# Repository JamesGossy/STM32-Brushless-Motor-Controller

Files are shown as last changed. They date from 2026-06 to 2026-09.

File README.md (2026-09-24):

<div align="center">

# STM32 Brushless Motor Controller

A custom four-layer motor controller with bare-metal field-oriented control on an STM32G474. The project includes the PCB design, C firmware, a motor simulator and a live control dashboard.

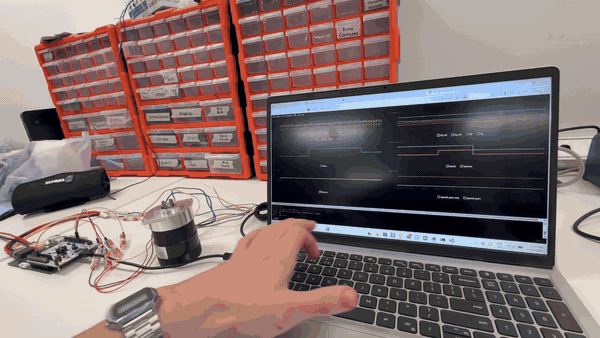
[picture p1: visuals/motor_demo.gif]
Bench demo of a real motor running alongside the live telemetry dashboard


*Real motor bench test with the live telemetry dashboard.*

</div>

## Engineering overview

- **Hardware:** a 57 × 75 mm PCB with six MOSFETs, three low-side current shunts, absolute encoder feedback and CAN connectivity.
- **Control:** 20 kHz d/q current loops and SVPWM, a 2 kHz speed loop, decoupling feedforward and field weakening.
- **Firmware:** bare-metal C using CMSIS headers, with register-level peripheral drivers and no STM32 HAL dependency. The application code also runs in the software-in-the-loop simulator.
- **Calibration and protection:** current-sense polarity and encoder calibration, stored settings, and checks for current, voltage, temperature, encoder and communication faults.
- **Tools:** a browser dashboard for commands and telemetry, plus unit tests and simulated motor/fault scenarios.

```mermaid
flowchart LR
    control["STM32G474<br/>Field-oriented control"]
    power["DRV8353S & MOSFETs<br/>Three-phase bridge"]
    motor["BLDC / PMSM motor"]
    control -->|PWM| power --> motor
    motor -->|Current & rotor position| control

    classDef controller fill:#eef2ff,stroke:#6366f1,color:#1e1b4b
    classDef drive fill:#ecfdf5,stroke:#059669,color:#064e3b
    class control controller
    class power,motor drive
```

## Hardware

<p align="center">
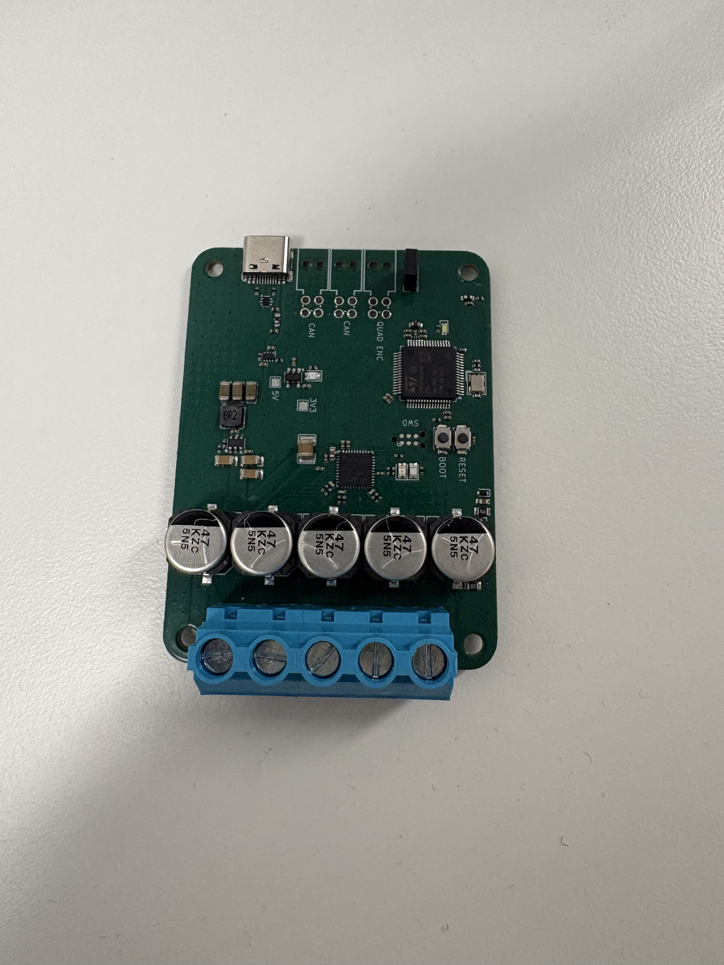
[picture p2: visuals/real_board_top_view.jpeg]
Top of the assembled board showing the MCU, gate driver and bulk capacitors
  
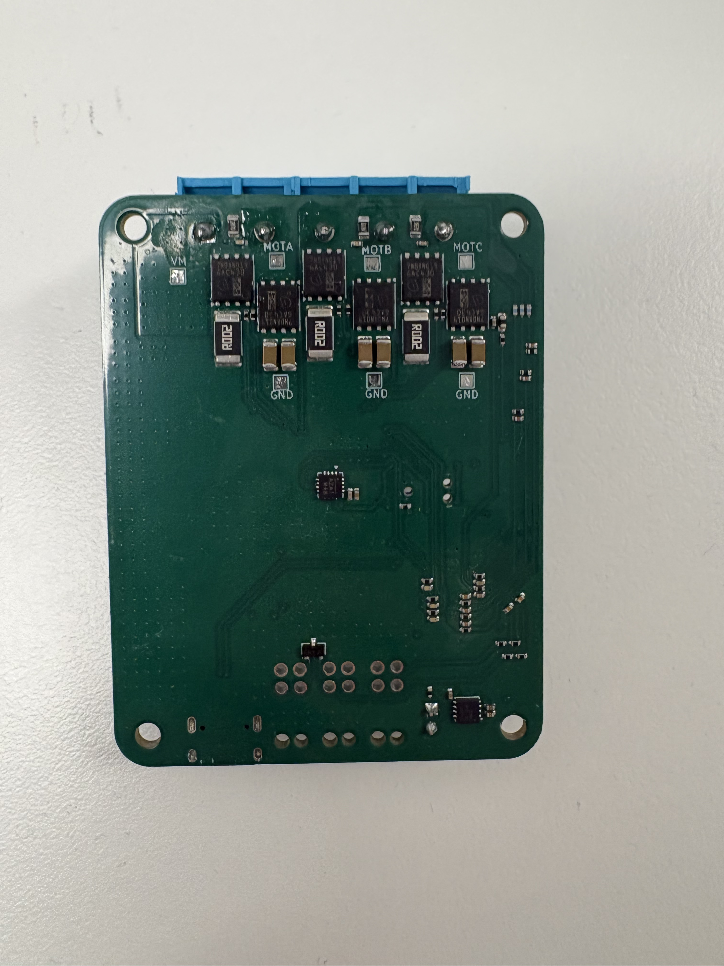
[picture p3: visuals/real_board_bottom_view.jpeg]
Bottom of the assembled board showing the MOSFET bridge and current shunts
  
</p>

| Item | Design |
| --- | --- |
| MCU | STM32G474RET6, 170 MHz |
| Gate driver | TI DRV8353S, configured over SPI |
| Input range | 12–60 V design target |
| Phase current | 25 A continuous design target; firmware defaults to a 20 A limit |
| MOSFETs | Six IAUCN08S7N019ATMA1, 80 V |
| Current sensing | Three 2 mΩ shunts with Kelvin connections |
| Position feedback | MA730 SPI encoder; external quadrature interface |
| PWM | HRTIM, 20 kHz, 200 ns dead time |
| Interfaces | CAN, USB CDC, UART and SWD |
| PCB | 57 × 75 mm, four layers |

The layout keeps gate-drive loops short, separates current-sense connections from power routing, and uses copper pours and via arrays to distribute current and heat. KiCad sources and manufacturing files are in [`controller_hardware/`](controller_hardware/).

## Live dashboard

<p align="center">
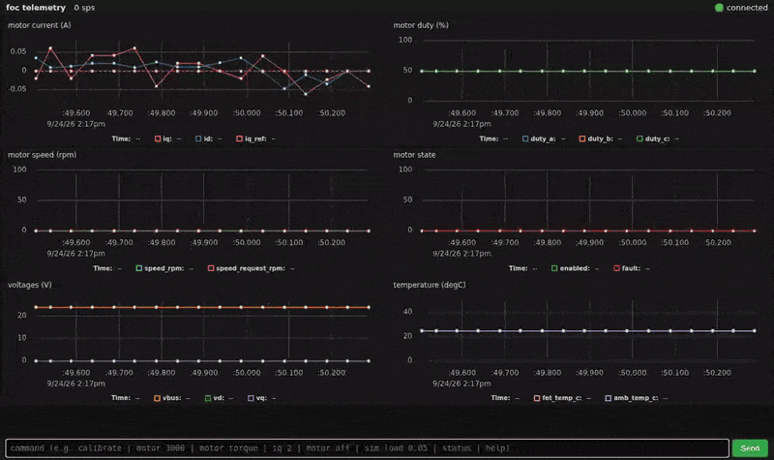
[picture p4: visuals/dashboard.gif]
Browser dashboard controlling the simulated motor and plotting telemetry
  
</p>

The dashboard connects to either the simulator or a board over USB. It shows motor telemetry and accepts commands for speed, torque, calibration and fault handling. The GIF above shows the simulator.

## Try the simulator

On Windows, run `controller_firmware\tools\setup.bat` to install missing tools, build the simulator and run tests. Then run `controller_firmware\tools\dashboard.bat` to open the dashboard.

For a manual build, install CMake, Ninja, a host C compiler and Python:

```sh
cd controller_firmware
cmake --preset sim
cmake --build --preset sim
ctest --preset sim
python -m pip install -r tools/dashboard/requirements.txt
python tools/dashboard/plot_motor.py --sim
```

Open [localhost:8988](http://localhost:8988). In the dashboard console, run `calibrate`, then `motor 3000` to request 3,000 rpm. Use `motor off` to stop. Simulator commands such as `sim load 0.1` and `sim lock on` exercise load response and fault handling.

## Build for the board

Install STM32CubeCLT and put its Arm compiler, CMake, Ninja and STM32 programmer on PATH. From `controller_firmware/`:

```sh
cmake --preset default
cmake --build --preset default
cmake --build build --target flash
```

Flashing uses ST-Link over SWD. To connect the dashboard to the board:

```sh
python tools/dashboard/plot_motor.py --serial COM5
```

Set the motor parameters and limits in [`app/config.h`](controller_firmware/app/config.h) before running hardware. Start with a current-limited supply and an unloaded motor, then run calibration before requesting motion.

## Validation and limits

C tests cover control maths, SVPWM, configuration, commands and telemetry. Software-in-the-loop tests exercise calibration, torque and speed response, field weakening, CAN control and fault handling. CI builds the firmware and runs simulator and dashboard tests on Linux and Windows.

The electrical ratings above are design targets; simulation does not establish continuous-current capability or thermal performance. This board revision has no on-board reverse-polarity protection, fuse or bus TVS.

## Code guide

| Location | Contents |
| --- | --- |
| [`controller_hardware/`](controller_hardware/) | KiCad schematics, PCB layout and manufacturing files |
| [`controller_firmware/app/`](controller_firmware/app/) | FOC, control loops, calibration, commands and telemetry |
| [`controller_firmware/hal/stm32g474/`](controller_firmware/hal/stm32g474/) | HRTIM, ADC, encoder, gate-driver, CAN and USB drivers |
| [`controller_firmware/sim/`](controller_firmware/sim/) | Simulated hardware interface, motor model and TCP server |
| [`controller_firmware/tests/`](controller_firmware/tests/) | Unit and motor simulation tests |
| [`controller_firmware/tools/dashboard/`](controller_firmware/tools/dashboard/) | Browser dashboard and Python bridge |

MIT licensed. Copyright © 2026 James Goss.

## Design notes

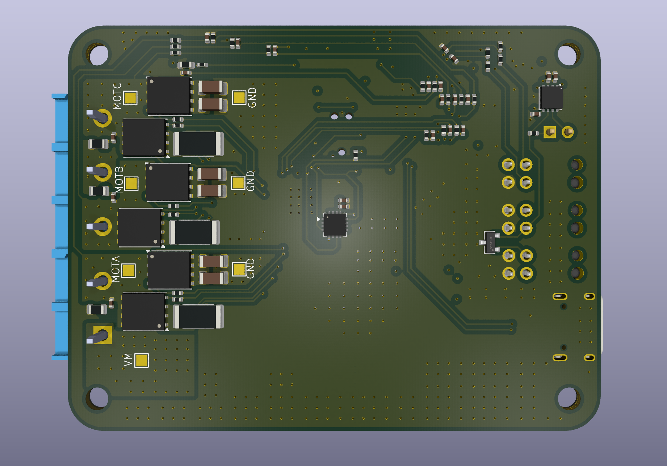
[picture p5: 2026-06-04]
visuals/bottom_view.png

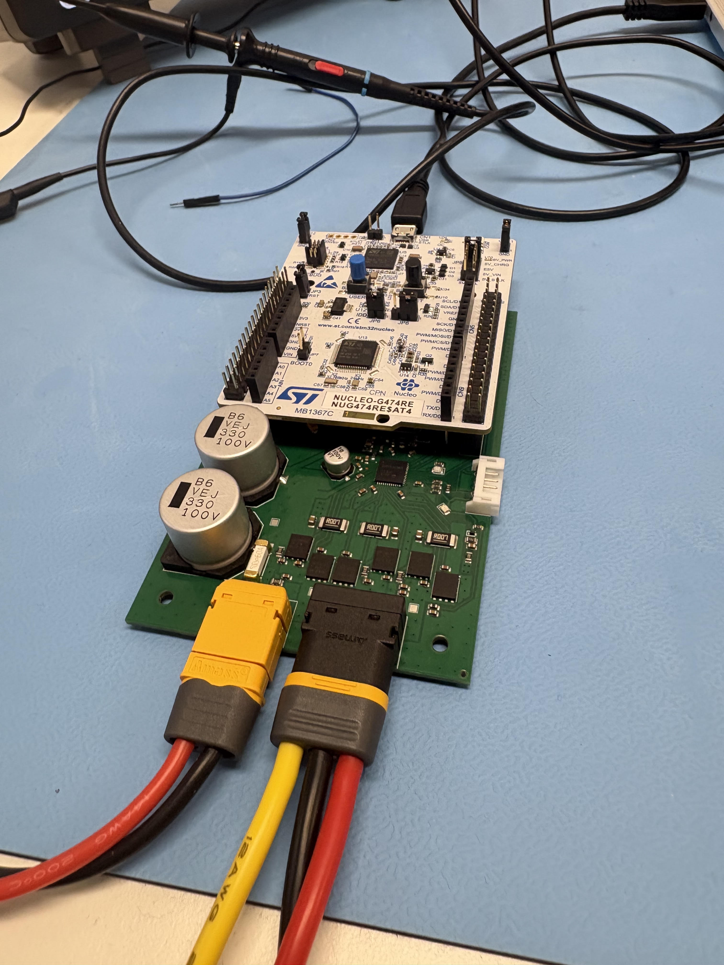
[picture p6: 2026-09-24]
visuals/rev1_board.jpg

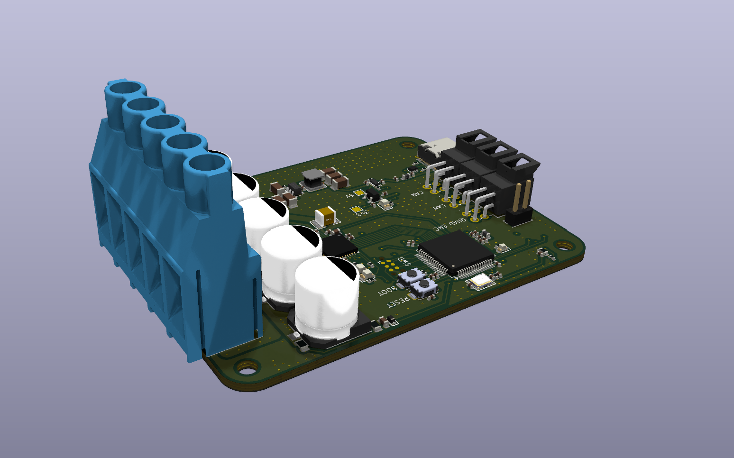
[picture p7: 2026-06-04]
visuals/side_view.png

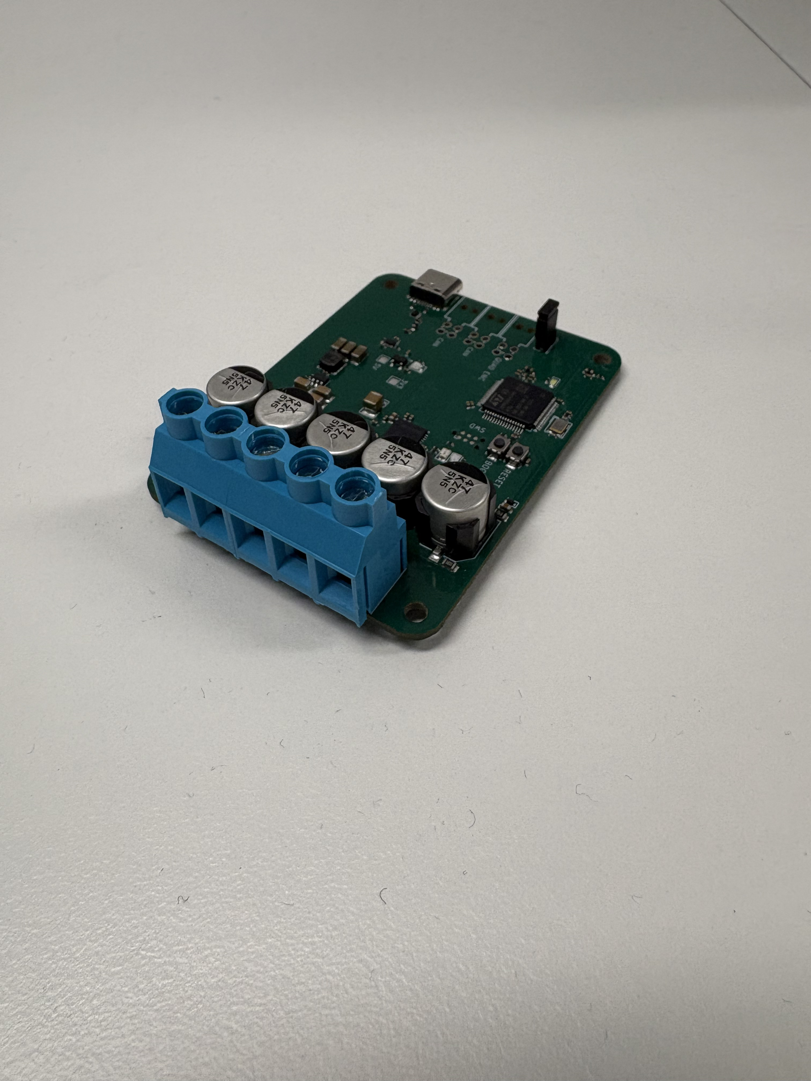
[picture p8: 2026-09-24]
visuals/real_board_angled_view.jpeg

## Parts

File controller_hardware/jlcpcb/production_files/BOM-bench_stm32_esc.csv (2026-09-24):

Comment | Designator | Footprint | LCSC | Quantity
100kΩ | R23,R51,R6 | R_0402 | C25741 | 3
100nF | C12,C30,C31,C33,C41,C46,C47,C48,C49,C5,C50,C53,C64,C65,C76,C83 | C_0402 | C1525 | 16
100nF | C11,C20,C22,C8 | C_0402 | C162178 | 4
100Ω | R1,R2,R42,R44,R45,R46,R47,R48,R49,R56 | R_0402 | C25076 | 10
1053141104 | CN1,CN2,CN3 | CONN-TH_4P-P2.50_MOLEX_1053141104 | C841207 | 3
10kΩ | R22,R24,R43,R50,R53 | R_0402 | C25744 | 5
10nF | C56,C57,C58 | C_0402 | C15195 | 3
10Ω | R25,R26,R27,R28,R31,R32 | R_0402 | C25077 | 6
120Ω | R14 | R_0402 | C25079 | 1
18pF | C85,C87 | C_0402 | C1549 | 2
19.1kΩ | R11 | R_0402 | C52036 | 1
1kΩ | R34,R36,R41,R55 | R_0402 | C11702 | 4
1nF | C51,C66,C67 | C_0402 | C1523 | 3
1nF | C21,C24,C25 | C_0402 | C527013 | 3
1uF | C23,C27,C28 | C_1206 | C13832 | 3
1uF | C13,C14,C15,C29,C36,C37,C42,C43,C45,C52,C93 | C_0402 | C52923 | 11
2.2nF | C39,C40 | C_0402 | C1531 | 2
2.2nF | C18,C26,C32 | C_0402 | C576731 | 3
2.2uF | C54,C55 | C_0402 | C72203 | 2
2.7Ω | R10,R13,R7 | R_0805 | C17532 | 3
20kΩ | R52,R54 | R_0402 | C25765 | 2
2mΩ | R12,R8,R9 | R_2512_6332Metric | C2994640 | 3
330Ω | R3,R4,R5 | R_0402 | C25104 | 3
383kΩ | R18 | R_0805 | C17652 | 1
383kΩ | R33,R35,R37 | R_0402 | C317011 | 3
4.7kΩ | R17,R21 | R_0402 | C25900 | 2
4.7uF | C68,C69,C70,C71,C72,C73 | C_1206 | C237304 | 6
4.7uF | C44 | C_0402 | C23733 | 1
47nF | C38,C6 | C_0603 | C559308 | 2
47nF | C61,C62,C63 | C_0402 | C82219 | 3
47uF | C10,C17,C19 | C_1206 | C172351 | 3
5.1kΩ | R29,R30 | R_0402 | C25905 | 2
56Ω | R15,R16,R20 | R_0402 | C25127 | 3
9.76kΩ | R19 | R_0805 | C17859 | 1
9.76kΩ | R38,R39,R40 | R_0402 | C2998101 | 3
DRV8353SRTAR | U4 | WQFN-40_L6.0-W6.0-P0.50-TL-EP4.5 | C701785 | 1
EEHZC1K470V | C1,C2,C3,C4,C7 | CAP-SMD_BD10.0-L10.3-W10.3-FD | C454280 | 5
FNR4020S8R2MT | L1 | IND-SMD_L4.0-W4.0_FNR40XXS | C167834 | 1
GRM32EC72A106KE05L | C9 | C1210 | C576517 | 1
Green | D2 | D_0805 | C2297 | 1
IAUCN08S7N019ATMA1 | Q1,Q2,Q3,Q4,Q5,Q6 | TDSON-8-1 | C33993693 | 6
LM66200DRLR | U5 | SOT-583-8_L2.1-W1.2-P0.50-LS1.6-BL | C3235556 | 1
LMR51635YDDCR | U1 | SOT-23-6_L2.9-W1.6-P0.95-LS2.8-BL | C45262770 | 1
PESD2CAN,215 | D3 | SOT-23-3_L2.9-W1.3-P1.90-LS2.4-BR | C75176 | 1
Red | D4 | D_0805 | C84256 | 1
TCAN1462VDRBRQ1 | U8 | DFN-8_L3.0-W3.0-P0.65-TL-EP2.4 | C5215833 | 1
Tactile Button, 160gf | S1,S2 | SW_TS-1088-AR02016 | C720477 | 2
Thermistor_NTC | TH1,TH2 | R_0603 | C2892547 | 2
White | D1 | D_0603 | C2290 | 1
X322524MOB4SI | X1 | CRYSTAL-SMD_4P-L3.2-W2.5-BL | C70590 | 1
Yellow | D6 | D_0805 | C2296 | 1
~ | FB1 | FB_0603 | C1002 | 1
~ | FB2 | FB_0603 | C14709 | 1
TestPoint | TP13 | TestPoint_Pad_1.5x1.5mm |  | 1
TestPoint | TP12 | TestPoint_Pad_1.5x1.5mm |  | 1
AP2112K-3.3 | U6 | SOT-23-5 |  | 1
USBLC6-2P6 | U20 | SOT-666 |  | 1
STM32G474RETx | U7 | LQFP-64_10x10mm_P0.5mm |  | 1
MA730 | U2 | QFN-16-1EP_3x3mm_P0.5mm_EP1.75x1.75mm |  | 1
USB_C_Receptacle_USB2.0_16P | J2 | USB_C_Receptacle_HRO_TYPE-C-31-M-12 |  | 1
Screw_Terminal_01x05 | J4 | CUI_TB005_-762-05BE |  | 1
Conn_02x01 | J1 | PinHeader_2x01_P2.54mm_Vertical |  | 1
TPD1E05U06DYA | U3 | D_SOD-523 |  | 1
TestPoint | TP9 | TestPoint_Pad_1.5x1.5mm |  | 1
TestPoint | TP8 | TestPoint_Pad_1.5x1.5mm |  | 1
TestPoint | TP1 | TestPoint_Pad_1.5x1.5mm |  | 1
TestPoint | TP11 | TestPoint_Pad_1.5x1.5mm |  | 1
TestPoint | TP10 | TestPoint_Pad_1.5x1.5mm |  | 1
TestPoint | TP7 | TestPoint_Pad_1.5x1.5mm |  | 1
TestPoint | TP6 | TestPoint_Pad_1.5x1.5mm |  | 1

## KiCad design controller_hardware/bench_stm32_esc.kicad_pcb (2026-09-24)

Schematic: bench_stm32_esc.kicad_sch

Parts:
C1, C2, C3, C4, C7: EEHZC1K470V; CAP-SMD_BD10.0-L10.3-W10.3-FD; MPN EEHZC1K470V; LCSC Part C454280
C5, C12, C30, C31, C33, C41, C46, C47, C48, C49, C50, C53, C64, C65, C76, C83: 100nF; C_0402; Voltage Rated 16V; Tolerance ±10%; Part CL05B104KO5NNNC; LCSC C1525
C6, C38: 47nF; C_0603; Voltage Rated 100V; Tolerance ±10%; Part 0603B473K101CT; LCSC C559308
C8, C11, C20, C22: 100nF; C_0402; Voltage Rated 100V; Tolerance ±10%; Part GRM155R62A104KE14D; LCSC C162178
C9: GRM32EC72A106KE05L; C1210; MPN GRM32EC72A106KE05L; LCSC Part C576517
C10, C17, C19: 47uF; C_1206; Voltage Rated 16V; Tolerance ±20%; Part 1206X476M160NT; LCSC C172351
C13, C14, C15, C29, C36, C37, C42, C43, C45, C52, C93: 1uF; C_0402; Voltage Rated 25V; Tolerance ±10%; Part CL05A105KA5NQNC; LCSC C52923
C18, C26, C32: 2.2nF; C_0402; Voltage Rated 100V; Tolerance ±10%; Part CC0402KRX7R0BB222; LCSC C576731
C21, C24, C25: 1nF; C_0402; Voltage Rated 100V; Tolerance ±10%; Part CC0402KRX7R0BB102; LCSC C527013
C23, C27, C28: 1uF; C_1206; Voltage Rated 100V; Tolerance ±10%; Part CL31B105KCHNNNE; LCSC C13832
C39, C40: 2.2nF; C_0402; Voltage Rated 50V; Tolerance ±10%; Part 0402B222K500NT; LCSC C1531
C44: 4.7uF; C_0402; Voltage Rated 10V; Tolerance ±20%; Part CL05A475MP5NRNC; LCSC C23733
C51, C66, C67: 1nF; C_0402; Voltage Rated 50V; Tolerance ±10%; Part 0402B102K500NT; LCSC C1523
C54, C55: 2.2uF; C_0402; Voltage Rated 25V; Tolerance ±20%; Part GRM155R61E225ME15D; LCSC C72203
C56, C57, C58: 10nF; C_0402; Voltage Rated 50V; Tolerance ±10%; Part CL05B103KB5NNNC; LCSC C15195
C61, C62, C63: 47nF; C_0402; Voltage Rated 50V; Tolerance ±10%; Part 0402B473K500NT; LCSC C82219
C68, C69, C70, C71, C72, C73: 4.7uF; C_1206; Voltage Rated 100V; Tolerance ±10%; Part GRM31CC72A475KE11L; LCSC C237304
C85, C87: 18pF; C_0402; Voltage Rated 50V; Tolerance ±5%; Part 0402CG180J500NT; LCSC C1549
CN1, CN2, CN3: 1053141104; CONN-TH_4P-P2.50_MOLEX_1053141104; MPN 1053141104; LCSC Part C841207
D1: White; D_0603; Part KT-0603W; LCSC C2290
D2: Green; D_0805; Part KT-0805G; LCSC C2297
D3: PESD2CAN,215; SOT-23-3_L2.9-W1.3-P1.90-LS2.4-BR; MPN PESD2CAN,215; LCSC Part C75176
D4: Red; D_0805; Forward Voltage (VF) 1.6V~2.6V; Part NCD0805R1; LCSC C84256
D6: Yellow; D_0805; Part KT-0805Y; LCSC C2296
FB1: FB_0603; Current Rating 200mA; Tolerance ±25%; Part GZ1608D601TF; LCSC C1002
FB2: FB_0603; Current Rating 2A; Tolerance ±25%; Part BLM18PG121SN1D; LCSC C14709
H1, H2, H3, H4: MountingHole; MountingHole_3.2mm_M3
J1: Conn_02x01; PinHeader_2x01_P2.54mm_Vertical
J2: USB_C_Receptacle_USB2.0_16P; USB_C_Receptacle_HRO_TYPE-C-31-M-12
J3: Conn_ARM_SWD_TagConnect_TC2030-NL; Tag-Connect_TC2030-IDC-NL_2x03_P1.27mm_Vertical
J4: Screw_Terminal_01x05; CUI_TB005_-762-05BE
L1: FNR4020S8R2MT; IND-SMD_L4.0-W4.0_FNR40XXS; MPN FNR4020S8R2MT; LCSC Part C167834
NT1, NT2, NT3, NT4, NT5, NT6: NetTie_2; NetTie-2_SMD_Pad0.5mm
NT7: NetTie_2; NetTie-2_SMD_Pad2.0mm
Q1, Q2, Q3, Q4, Q5, Q6: IAUCN08S7N019ATMA1; TDSON-8-1; LCSC C33993693
R1, R2, R42, R44, R45, R46, R47, R48, R49, R56: 100Ω; R_0402; Overload Voltage (Max) 50V; Tolerance ±1%; Part 0402WGF1000TCE; LCSC C25076
R3, R4, R5: 330Ω; R_0402; Overload Voltage (Max) 50V; Tolerance ±1%; Part 0402WGF3300TCE; LCSC C25104
R6, R23, R51: 100kΩ; R_0402; Overload Voltage (Max) 50V; Tolerance ±1%; Part 0402WGF1003TCE; LCSC C25741
R7, R10, R13: 2.7Ω; R_0805; Overload Voltage (Max) 150V; Tolerance ±1%; Part 0805W8F270KT5E; LCSC C17532
R8, R9, R12: 2mΩ; R_2512_6332Metric; Part No HoLLR2512-3W-2mR-1%; LCSC C2994640
R11: 19.1kΩ; R_0402; Overload Voltage (Max) 50V; Part 0402WGF1912TCE; LCSC C52036
R14: 120Ω; R_0402; Overload Voltage (Max) 50V; Tolerance ±1%; Part 0402WGF1200TCE; LCSC C25079
R15, R16, R20: 56Ω; R_0402; Overload Voltage (Max) 50V; Tolerance ±1%; Part 0402WGF560JTCE; LCSC C25127
R17, R21: 4.7kΩ; R_0402; Overload Voltage (Max) 50V; Tolerance ±1%; Part 0402WGF4701TCE; LCSC C25900
R18: 383kΩ; R_0805; Overload Voltage (Max) 150V; Tolerance ±1%; Part 0805W8F3833T5E; LCSC C17652
R19: 9.76kΩ; R_0805; Overload Voltage (Max) 150V; Tolerance ±1%; Part 0805W8F9761T5E; LCSC C17859
R22, R24, R43, R50, R53: 10kΩ; R_0402; Overload Voltage (Max) 50V; Tolerance ±1%; Part 0402WGF1002TCE; LCSC C25744
R25, R26, R27, R28, R31, R32: 10Ω; R_0402; Overload Voltage (Max) 50V; Tolerance ±1%; Part 0402WGF100JTCE; LCSC C25077
R29, R30: 5.1kΩ; R_0402; Overload Voltage (Max) 50V; Tolerance ±1%; Part 0402WGF5101TCE; LCSC C25905
R33, R35, R37: 383kΩ; R_0402; Overload Voltage (Max) 75V; Tolerance ±1%; Part RK73H1ETTP3833F; LCSC C317011
R34, R36, R41, R55: 1kΩ; R_0402; Overload Voltage (Max) 50V; Tolerance ±1%; Part 0402WGF1001TCE; LCSC C11702
R38, R39, R40: 9.76kΩ; R_0402; Overload Voltage (Max) 50V; Tolerance ±1%; Part FRC0402F9761TS; LCSC C2998101
R52, R54: 20kΩ; R_0402; Overload Voltage (Max) 50V; Tolerance ±1%; Part 0402WGF2002TCE; LCSC C25765
S1, S2: Tactile Button, 160gf; SW_TS-1088-AR02016; Voltage Rating (Dc) 12V; Part TS-1088-AR02016; LCSC C720477
TH1, TH2: Thermistor_NTC; R_0603; Part No KNTC0603/10KF3950; LCSC C2892547
TP1, TP6, TP7, TP8, TP9, TP10, TP11, TP12, TP13: TestPoint; TestPoint_Pad_1.5x1.5mm
U1: LMR51635YDDCR; SOT-23-6_L2.9-W1.6-P0.95-LS2.8-BL; MPN LMR51635YDDCR; LCSC Part C45262770
U2: MA730; QFN-16-1EP_3x3mm_P0.5mm_EP1.75x1.75mm
U3: TPD1E05U06DYA; D_SOD-523
U4: DRV8353SRTAR; WQFN-40_L6.0-W6.0-P0.50-TL-EP4.5; MPN DRV8353SRTAR; LCSC Part C701785
U5: LM66200DRLR; SOT-583-8_L2.1-W1.2-P0.50-LS1.6-BL; MPN LM66200DRLR; LCSC Part C3235556
U6: AP2112K-3.3; SOT-23-5
U7: STM32G474RETx; LQFP-64_10x10mm_P0.5mm
U8: TCAN1462VDRBRQ1; DFN-8_L3.0-W3.0-P0.65-TL-EP2.4; MPN TCAN1462VDRBRQ1; LCSC Part C5215833
U20: USBLC6-2P6; SOT-666
X1: X322524MOB4SI; CRYSTAL-SMD_4P-L3.2-W2.5-BL; MPN X322524MOB4SI; LCSC Part C70590

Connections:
5V_OR: C31.2, C36.1, C43.1, CN3.2, TP12.1 (1_1), U5.2 (VOUT), U5.7 (VOUT), U6.1 (VIN), U6.3 (EN), U8.3 (VCC)
+3V3: C11.1, C29.1, C30.1, C33.2, C44.1, C45.1, C46.1, C47.1, C48.1, C49.1, C53.1, C93.1, D4.2, D6.2, FB1.2, J3.1 (VCC), R17.1, R21.1, R22.1, R23.1, R43.1, R55.1, S2.1 (A), TP13.1 (1_1), U2.13 (VDD), U4.24 (VREF), U6.5 (VOUT), U7.1 (VBAT), U7.16 (VDD), U7.32 (VDD), U7.48 (VDD), U7.64 (VDD), U8.5 (NC/VIO)
+3V3A: C50.1, C52.1, C83.1, FB1.1, U7.28 (VREF+), U7.29 (VDDA)
+5V_BUCK: C10.1, C17.1, C19.1, C37.1, L1.2, R6.1, U5.6 (VIN2)
+5V_USB: C42.1, C55.1, FB2.2, U5.3 (VIN1)
/AMB_TMP: C12.1, R21.2, R48.1, TH2.1
/AMB_TMP_ADC: C64.1, R48.2, U7.10 (PC2)
/BOOT0: R24.1, S2.2 (B), U7.61 (PB8)
/CANH: CN1.4, CN2.4, D3.1, J1.2, U8.7 (CANH)
/CANL: CN1.3, CN2.3, D3.2, R14.1, U8.6 (CANL)
/CAN_RX: U7.58 (PB5), U8.4 (RXD)
/CAN_TX: U7.59 (PB6), U8.1 (TXD)
/CB: C22.2, U1.6 (CB)
/CC1: J2.A5 (CC1), R30.1
/CC2: J2.B5 (CC2), R29.1
/CPH: C6.2, U4.2 (CPH)
/CPL: C6.1, U4.1 (CPL)
/D+: J2.A6 (D+), J2.B6 (D+), U20.1 (I/O2)
/D-: J2.A7 (D-), J2.B7 (D-), U20.6 (I/O1)
/DVDD: C15.1, U4.38 (DVDD)
/ENABLE: D2.2, U4.31 (ENABLE), U7.57 (PB4)
/ENC_CS: U2.5 (~CS), U7.33 (PB11)
/FAULT: R4.2, R22.2, U4.26 (nFAULT)
/FB: R6.2, R11.1, U1.1 (FB)
/GD_CS: R43.2, U4.30 (nSCS), U7.52 (PC10)
/GHA: R27.1, U4.6 (GHA)
/GHA_R: Q1.4 (G), R27.2
/GHB: R26.1, U4.15 (GHB)
/GHB_R: Q3.4 (G), R26.2
/GHC: R25.1, U4.16 (GHC)
/GHC_R: Q5.4 (G), R25.2
/GLA: R32.1, U4.8 (GLA)
/GLA_R: Q2.4 (G), R32.2
/GLB: R31.1, U4.13 (GLB)
/GLB_R: Q4.4 (G), R31.2
/GLC: R28.1, U4.18 (GLC)
/GLC_R: Q6.4 (G), R28.2
/HEARBEAT: D1.2, U7.18 (PA4)
/HSE_IN: C87.1, U7.5 (PF0), X1.3 (OSC2)
/HSE_OUT: C85.1, U7.6 (PF1), X1.1 (OSC1)
/IA: C56.1, R20.1, U7.37 (PB15)
/IB: C57.1, R16.1, U7.36 (PB14)
/IC: C58.1, R15.1, U7.35 (PB13)
/INHA: U4.32 (INHA), U7.43 (PA9)
/INHB: U4.34 (INHB), U7.41 (PC9)
/INHC: U4.36 (INHC), U7.39 (PC7)
/INLA: U4.33 (INLA), U7.42 (PA8)
/INLB: U4.35 (INLB), U7.40 (PC8)
/INLC: U4.37 (INLC), U7.38 (PC6)
/MOTA: C18.1, J4.2, NT1.2, Q1.1 (S), Q1.2 (S), Q1.3 (S), Q2.5 (D), R33.1, TP8.1 (1_1)
/MOTB: C26.1, J4.3, NT3.2, Q3.1 (S), Q3.2 (S), Q3.3 (S), Q4.5 (D), R35.1, TP6.1 (1_1)
/MOTC: C32.1, J4.5, NT5.2, Q5.1 (S), Q5.2 (S), Q5.3 (S), Q6.5 (D), R37.1, TP7.1 (1_1)
/NRST: C76.1, J3.3 (~RESET), S1.2 (B), U7.7 (PG10)
/ON: R51.1, U5.4 (~ON)
/PHASE_TMP: C5.1, R17.2, R49.1, TH1.1
/PHASE_TMP_ADC: C65.1, R49.2, U7.11 (PC3)
/QUAD_CH1: C40.1, R50.2, R52.1, U7.12 (PA0)
/QUAD_CH1_CONN: CN3.4, R50.1
/QUAD_CH2: C39.1, R53.2, R54.1, U7.13 (PA1)
/QUAD_CH2_CONN: CN3.3, R53.1
/SHA: NT1.1, U4.7 (SHA)
/SHB: NT3.1, U4.14 (SHB)
/SHC: NT5.1, U4.17 (SHC)
/SNA: NT2.1, R2.2
/SNA_FILT: C21.2, R2.1, U4.10 (SNA)
/SNB: NT4.1, R44.2
/SNB_FILT: C24.2, R44.1, U4.11 (SNB)
/SNC: NT6.1, R46.2
/SNC_FILT: C25.2, R46.1, U4.20 (SNC)
/SOA: R20.2, U4.23 (SOA)
/SOB: R16.2, U4.22 (SOB)
/SOC: R15.2, U4.21 (SOC)
/SPA: Q2.1 (S), Q2.2 (S), Q2.3 (S), R1.2, R8.1
/SPA_FILT: C21.1, R1.1, U4.9 (SPA)
/SPB: Q4.1 (S), Q4.2 (S), Q4.3 (S), R9.1, R42.2
/SPB_FILT: C24.1, R42.1, U4.12 (SPB)
/SPC: Q6.1 (S), Q6.2 (S), Q6.3 (S), R12.1, R45.2
/SPC_FILT: C25.1, R45.1, U4.19 (SPC)
/SPI_MISO: R55.2, U2.7 (MISO), U4.27 (SDO), U7.20 (PA6)
/SPI_MOSI: U2.4 (MOSI), U4.28 (SDI), U7.21 (PA7)
/SPI_SCK: U2.12 (SCLK), U4.29 (SCLK), U7.19 (PA5)
/ST: R23.2, U5.8 (ST)
/SW: C22.1, L1.1, U1.5 (SW)
/SWCLK: J3.4 (SWCLK), U7.50 (PA14)
/SWDIO: J3.2 (SWDIO), U7.49 (PA13)
/SWO: J3.6 (SWO), U7.56 (PB3)
/USB_D+: U7.46 (PA12), U20.3 (I/O2)
/USB_D-: U7.45 (PA11), U20.4 (I/O1)
/USB_VBUS: C54.1, FB2.1, J2.A4 (VBUS), J2.A9 (VBUS), J2.B4 (VBUS), J2.B9 (VBUS), U20.5 (VBUS)
/VA_ADC: C51.1, R41.1, U7.26 (PB2)
/VB_ADC: C66.1, R36.1, U7.25 (PB1)
/VCP: C14.1, U4.5 (VCP)
/VC_ADC: C67.1, R34.1, U7.24 (PB0)
/VDC_ADC: C41.1, R47.2, U7.9 (PC1)
/VDRAIN: C14.2, NT7.1, U4.4 (VDRAIN)
/VGLS: C13.1, U4.40 (VGLS)
/VSENA: C61.1, R33.2, R40.1, R41.2
/VSENB: C62.1, R35.2, R36.2, R39.1
/VSENC: C63.1, R34.2, R37.2, R38.1
/VSENVM: C38.1, R18.2, R19.1, R47.1, U3.1 (I/O)
GND: C1.2, C2.2, C3.2, C4.2, C5.2, C7.2, C8.2, C9.1, C10.2, C11.2, C12.2, C13.2, C15.2, C17.2, C19.2, C20.2, C23.1, C27.1, C28.1, C29.2, C30.2, C31.1, C33.1, C36.2, C37.2, C38.2, C39.2, C40.2, C41.2, C42.2, C43.2, C44.2, C45.2, C46.2, C47.2, C48.2, C49.2, C50.2, C51.2, C52.2, C53.2, C54.2, C55.2, C56.2, C57.2, C58.2, C61.2, C62.2, C63.2, C64.2, C65.2, C66.2, C67.2, C68.2, C69.2, C70.2, C71.2, C72.2, C73.2, C76.2, C83.2, C85.2, C87.2, C93.2, CN1.1, CN1.2, CN2.1, CN2.2, CN3.1, D3.3, J2.A1 (GND), J2.A12 (GND), J2.B1 (GND), J2.B12 (GND), J2.SH (SHIELD), J3.5 (GND), J4.4, NT2.2, NT4.2, NT6.2, R3.2, R5.2, R7.2, R8.2, R9.2, R10.2, R11.2, R12.2, R13.2, R19.2, R24.2, R29.2, R30.2, R38.2, R39.2, R40.2, R51.2, R52.2, R54.2, R56.2, S1.1 (A), TH1.2, TH2.2, TP9.1 (1_1), TP10.1 (1_1), TP11.1 (1_1), U1.4 (GND), U2.8 (GND), U2.10 (TEST), U2.17 (PAD), U3.2 (GND), U4.25 (AGND), U4.39 (GND), U4.41 (EP), U5.1 (GND), U5.5 (GND), U6.2 (GND), U7.15 (VSS), U7.27 (VSSA), U7.31 (VSS), U7.47 (VSS), U7.63 (VSS), U8.2 (GND), U8.8 (STB), U8.9 (EP), U20.2 (GND), X1.2 (GND), X1.4 (GND)
unnamed: C18.2, R7.1
unnamed: C26.2, R10.1
unnamed: C32.2, R13.1
unnamed: D1.1, R56.1
unnamed: D2.1, R3.1
unnamed: D4.1, R4.1
unnamed: D6.1, R5.1
unnamed: J1.1, R14.2
VM: C1.1, C2.1, C3.1, C4.1, C7.1, C8.1, C9.2, C20.1, C23.2, C27.2, C28.2, C68.1, C69.1, C70.1, C71.1, C72.1, C73.1, J4.1, NT7.2, Q1.5 (D), Q3.5 (D), Q5.5 (D), R18.1, TP1.1 (1_1), U1.2 (EN), U1.3 (VIN), U4.3 (VM)

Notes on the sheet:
Phase A
CAN Transciever + Connectors
VM to 5V Buck
Power ORing + LDO
Crystal
STM32G474
Quadrature Encoder Connector
LED Indicators
DRV8353
Input Voltage
Phase B
SPI MA730 Encoder
Temp Sensing
Phase C
Mounting Holes
USB-C Connector
SWD Connector

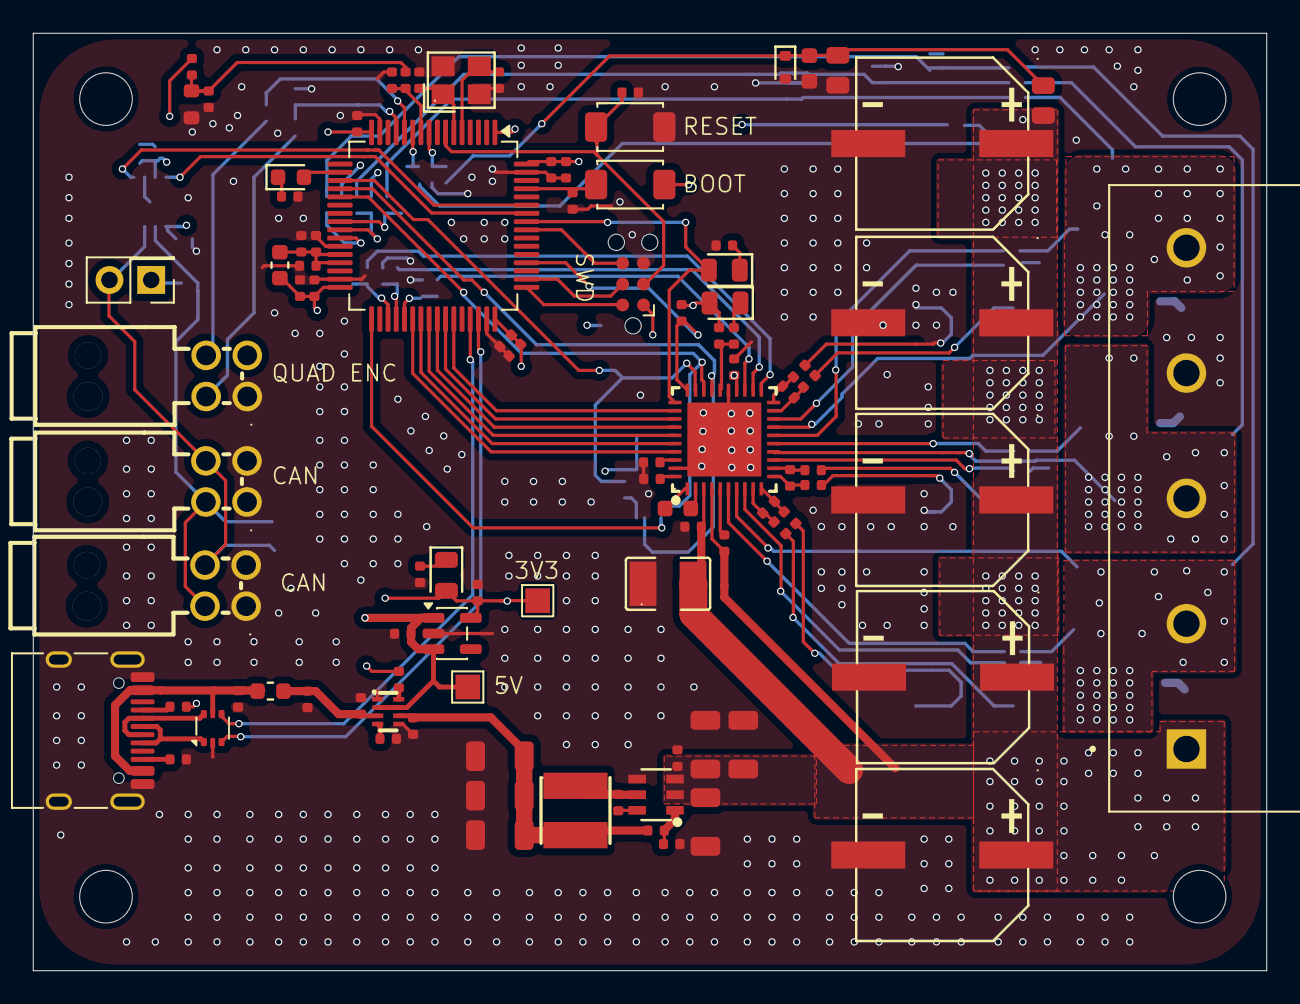
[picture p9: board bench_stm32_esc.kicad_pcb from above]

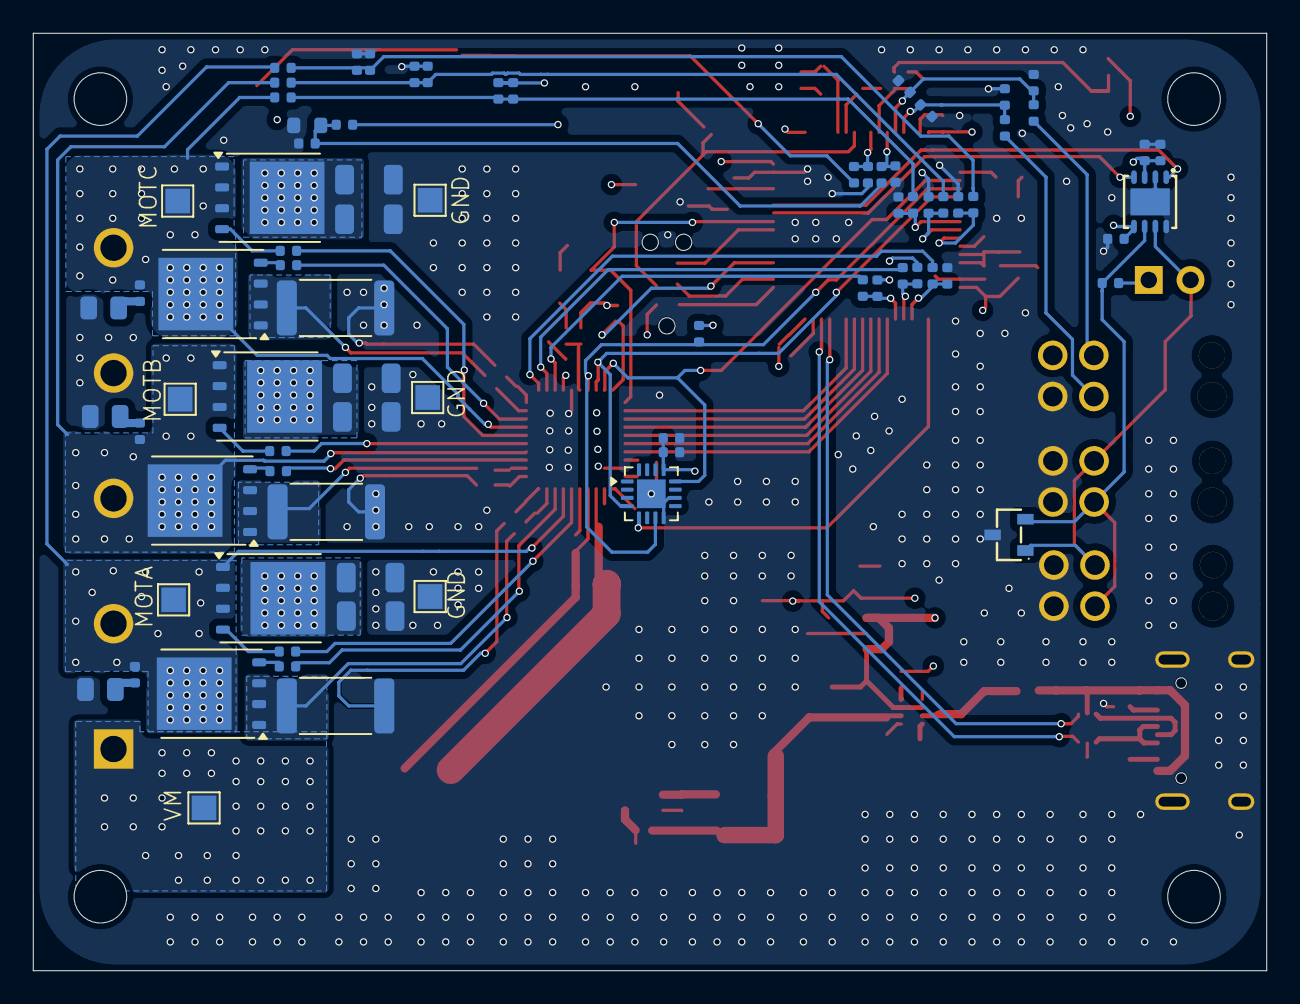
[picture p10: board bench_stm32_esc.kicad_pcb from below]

Board: 4 copper layers, 75.0 x 57.0 mm, 184 parts (81 on the bottom side), 110 nets.

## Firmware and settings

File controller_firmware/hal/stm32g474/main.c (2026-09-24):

/*
 * main.c - firmware entry point. Brings up the board and application, then
 * runs the main loop. All motor control happens in the ADC interrupt.
 */
#include "hal.h"
#include "app.h"

int main(void)
{
    hal_init();
    app_init();
    hal_start();

    uint32_t last = hal_millis();
    for (;;) {
        app_poll();

        uint32_t now = hal_millis();
        if (now != last) {
            last = now;
            app_tick();
        }
    }
}

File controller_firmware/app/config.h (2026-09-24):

/*
 * config.h - motor, board and tuning parameters.
 *
 * Everything that changes between motors or boards lives here. The PI gains
 * are calculated from these values at boot, so normally only this file needs
 * editing when switching motors.
 */
#pragma once

/* ---- Motor ---- */
#define POLE_PAIRS      2
#define RS              0.0628f     /* phase resistance, ohm */
#define LD              0.147e-3f   /* d-axis inductance, H */
#define LQ              0.144e-3f   /* q-axis inductance, H */
#define FLUX_PM         0.00772f    /* magnet flux linkage, Wb */
#define KT              0.0232f     /* torque constant, Nm/A */
#define J_ROTOR         19.45e-6f   /* rotor inertia, kg m^2 (add load inertia here) */
#define B_VISC          0.0371e-3f  /* viscous friction, Nm s/rad */

/* ---- Limits and protection ---- */
#define VBUS_NOMINAL    24.0f
#define I_MAX           20.0f       /* peak phase current limit, A */
#define I_TRIP          30.0f       /* instantaneous overcurrent trip, A */
#define SPEED_MAX       1047.2f     /* mechanical rad/s (10k rpm) */
#define SPEED_RAMP      5000.0f     /* speed setpoint slew rate, rad/s^2 */
#define VBUS_MIN        8.0f
#define VBUS_MAX        60.0f
#define TEMP_MAX        100.0f      /* FET temperature trip, degC */
#define STALL_SPEED     5.0f        /* below this with full current demand ... */
#define STALL_MS        500         /* ... for this long = stall fault */
#define I_SUM_FAULT     5.0f        /* |ia + ib + ic| above this = sensor fault, A */

/* ---- Timing ---- */
#define F_SYS           170000000u
#define F_PWM           20000u
#define TS              (1.0f / F_PWM)
#define SPEED_DIV       10          /* speed loop runs every 10th current loop (2 kHz) */
#define TS_SPEED        (TS * SPEED_DIV)
#define PWM_PER         (F_SYS * 4u / F_PWM)   /* HRTIM ticks per period at x4 clock = 34000 */
#define DEADTIME_NS     200

/* ---- Loop tuning ---- */
#define CURRENT_BW_HZ   1000.0f
#define SPEED_BW_HZ     50.0f
#define PLL_BW_HZ       300.0f
#define DELAY_COMP      1.5f        /* PWM delay to compensate, in periods */

/* ---- Field weakening ---- */
#define FW_VFRAC        0.90f       /* keep |Vdq| at this fraction of the voltage limit */
#define FW_KP           0.05f       /* A/V */
#define FW_KI           150.0f      /* A/(V s) */
#define FW_ID_MIN       (-15.0f)    /* most negative d-axis current allowed, A */

/* ---- Modulation ---- */
#define MOD_MAX         0.95f       /* fraction of the linear SVPWM limit Vbus/sqrt(3) */
#define DUTY_MIN        0.02f
#define DUTY_MAX        0.98f

/* ---- Sensing ---- */
#define ADC_VREF        3.3f
#define R_SHUNT         0.002f
#define CSA_GAIN        20.0f
#define I_PER_COUNT     (ADC_VREF / 4096.0f / (CSA_GAIN * R_SHUNT))
#define V_PER_COUNT     (ADC_VREF / 4096.0f * (383.0f + 9.76f) / 9.76f)
#define NTC_R_TOP       4700.0f
#define NTC_R25         10000.0f
#define NTC_BETA        3950.0f

/* ---- Calibration ---- */
#define CAL_CURRENT     5.0f        /* alignment current, A */
#define CAL_VMAX        3.0f        /* voltage ceiling while ramping up, V */
#define CAL_EREVS       4           /* electrical revolutions per sweep */
#define CAL_SWEEP_S     2.0f        /* seconds per sweep */

/* ---- Communication ---- */
#define CAN_NODE_ID     1
#define CAN_TIMEOUT_MS  250         /* CAN setpoints must refresh this often */
#define CAN_TELEM_MS    10
#define TELEM_MS        5           /* serial telemetry period */

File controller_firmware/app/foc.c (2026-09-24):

/*
 * foc.c - the 20 kHz control interrupt.
 *
 * Each PWM period the HAL hands over a fresh current/voltage/encoder sample.
 * This file turns it into phase currents, rotor angle and speed, handles
 * state changes and protection, and then runs either calibration or the
 * current/speed loops (loops.c).
 */
#include "foc.h"
#include "hal.h"
#include "svpwm.h"
#include "loops.h"
#include "calib.h"
#include "cfg.h"
#include "trig.h"
#include "config.h"
#include <math.h>

#define BOOT_SKIP     1000   /* samples to wait before measuring offsets */
#define BOOT_SAMPLES  4096   /* samples averaged for the offsets */

foc_t foc;

static float pll_kp, pll_ki, pll_theta, pll_speed;
static int pll_started;
static float offset_a, offset_b, offset_c;
static uint32_t isr_count;
static int sum_errors, encoder_errors;

/* Set up the PLL gains and control loops. Called once before the ISR starts. */
void foc_init(void)
{
    trig_init();
    loops_init();

    float wn = TWO_PI * PLL_BW_HZ;
    pll_kp = 2.0f * wn;     /* critically damped */
    pll_ki = wn * wn;

    foc.i_limit = I_MAX;
    foc.speed_limit = SPEED_MAX;
    foc.state = ST_BOOT;
}

/* Number of control interrupts so far (used by the watchdog check). */
uint32_t foc_isr_count(void) { return isr_count; }

/* Restart the PLL at a known angle, e.g. after calibration changes direction. */
void foc_pll_reset(float theta_m)
{
    pll_theta = theta_m;
    pll_speed = 0.0f;
}

/* Latch a fault and turn the power stage off. Safe from any context. */
void foc_fault(uint16_t f)
{
    uint32_t irq = hal_irq_save();
    hal_pwm_enable(0);
    foc.faults |= f;
    if (foc.state != ST_BOOT) foc.state = ST_FAULT;
    hal_irq_restore(irq);
}

/* Clear all faults and go back to idle. */
void foc_clear_faults(void)
{
    uint32_t irq = hal_irq_save();
    foc.faults = 0;
    sum_errors = encoder_errors = 0;
    if (foc.state == ST_FAULT) foc.state = ST_IDLE;
    hal_irq_restore(irq);
}

/* Average the current sense offsets while the PWM is off. */
static void measure_offsets(const hal_sample_t *s)
{
    foc.req = REQ_NONE;
    if (isr_count <= BOOT_SKIP) return;

    offset_a += s->ia;
    offset_b += s->ib;
    offset_c += s->ic;
    if (isr_count < BOOT_SKIP + BOOT_SAMPLES) return;

    offset_a /= BOOT_SAMPLES;
    offset_b /= BOOT_SAMPLES;
    offset_c /= BOOT_SAMPLES;

    /* the amplifiers should sit near mid-scale (2048) */
    if (fabsf(offset_a - 2048.0f) > 150.0f || fabsf(offset_b - 2048.0f) > 150.0f ||
        fabsf(offset_c - 2048.0f) > 150.0f)
        foc.faults |= F_OFFSET;

    foc.state = foc.faults ? ST_FAULT : ST_IDLE;
}

/* Convert raw ADC counts to amps and rebuild the least trustworthy phase. */
static void read_currents(const hal_sample_t *s, float *ia_raw)
{
    float sign = (float)cfg.cur_sign;
    *ia_raw = (s->ia - offset_a) * I_PER_COUNT;
    float ia = *ia_raw * sign;
    float ib = (s->ib - offset_b) * I_PER_COUNT * sign;
    float ic = (s->ic - offset_c) * I_PER_COUNT * sign;

    /* all three are valid when no duty is near 100 %: check they sum to zero */
    int active = foc.state == ST_RUN || foc.state == ST_CAL;
    if (active && maxf(duty[0], maxf(duty[1], duty[2])) < 0.8f) {
        if (fabsf(ia + ib + ic) > I_SUM_FAULT) {
            if (++sum_errors > 100) foc_fault(F_CURRENT_SUM);
        } else if (sum_errors) {
            sum_errors--;
        }
    }

    /* the phase with the highest duty has the shortest low-side window,
       so replace it with minus the sum of the other two */
    if (duty[0] >= duty[1] && duty[0] >= duty[2]) ia = -ib - ic;
    else if (duty[1] >= duty[2])                  ib = -ia - ic;
    else                                          ic = -ia - ib;

    foc.ia = ia;
    foc.ib = ib;
    foc.ic = ic;
}

/* Mechanical angle from the encoder, and speed from a PLL tracking it. */
static float read_angle(uint16_t enc)
{
    float raw = enc * (TWO_PI / 65536.0f);
    float theta_m = cfg.enc_dir > 0 ? raw : wrap_2pi(TWO_PI - raw);

    if (!pll_started) {
        pll_theta = theta_m;
        pll_started = 1;
    }

    float err = wrap_pi(theta_m - pll_theta);

    /* a real rotor can't jump: a large error for several samples is a bad encoder */
    if (foc.state == ST_RUN && fabsf(err) > 0.5f) {
        if (++encoder_errors > 3) foc_fault(F_ENCODER);
    } else {
        encoder_errors = 0;
    }

    pll_speed += pll_ki * TS * err;
    pll_theta = wrap_2pi(pll_theta + TS * (pll_speed + pll_kp * err));

    foc.theta_m = theta_m;
    foc.omega_m = pll_speed;
    return raw;
}

/* Put the drive into run mode with fresh loop state. */
static void start_run(uint8_t mode)
{
    loops_reset();
    foc.mode = mode;
    svpwm_reset();
    foc.state = ST_RUN;
    hal_pwm_enable(1);
}

/* Act on a state change requested by the main loop. */
static void handle_request(void)
{
    uint8_t req = foc.req;
    if (req == REQ_NONE) return;
    foc.req = REQ_NONE;

    int can_start = foc.state == ST_IDLE && !foc.faults && foc.vbus >= VBUS_MIN;

    if (req == REQ_IDLE) {
        if (foc.state == ST_RUN || foc.state == ST_CAL) {
            hal_pwm_enable(0);
            foc.state = ST_IDLE;
        }
    } else if (req == REQ_CAL) {
        if (can_start) cal_start();
    } else {
        uint8_t mode = req == REQ_SPEED ? MODE_SPEED : MODE_TORQUE;
        if (!cfg.cal_valid) {
            foc_fault(F_NOT_CAL);
        } else if (can_start) {
            start_run(mode);
        } else if (foc.state == ST_RUN && foc.mode != mode) {
            if (mode == MODE_SPEED) loops_speed_bumpless(pll_speed);
            foc.mode = mode;
        }
    }
}

/* Called by the HAL every PWM period with the latest sample. */
void app_control_isr(const hal_sample_t *s)
{
    isr_count++;
    foc.vbus = s->vbus * V_PER_COUNT;

    if (foc.state == ST_BOOT) {
        measure_offsets(s);
        return;
    }

    float ia_raw;
    read_currents(s, &ia_raw);
    float raw_angle = read_angle(s->enc);

    if (fabsf(foc.ia) > I_TRIP || fabsf(foc.ib) > I_TRIP || fabsf(foc.ic) > I_TRIP)
        foc_fault(F_OVERCURRENT);
    if (foc.vbus > VBUS_MAX)
        foc_fault(F_OVERVOLT);

    /* Clarke + Park */
    float theta_e = wrap_2pi(POLE_PAIRS * foc.theta_m - cfg.enc_offset);
    float sn, cs;
    sincos_lut(theta_e, &sn, &cs);
    float ibeta = (foc.ib - foc.ic) * INV_SQRT3;
    float id = foc.ia * cs + ibeta * sn;
    float iq = -foc.ia * sn + ibeta * cs;
    foc.theta_e = theta_e;
    foc.id = id;
    foc.iq = iq;

    handle_request();

    if (foc.state == ST_CAL) {
        if (foc.vbus < VBUS_MIN) foc_fault(F_UNDERVOLT);
        else cal_run(ia_raw, raw_angle);
        return;
    }
    if (foc.state != ST_RUN) return;

    if (foc.vbus < VBUS_MIN) { foc_fault(F_UNDERVOLT); return; }
    if (fabsf(pll_speed) > 1.25f * SPEED_MAX) { foc_fault(F_OVERSPEED); return; }

    loops_run(id, iq, theta_e, POLE_PAIRS * pll_speed);
}

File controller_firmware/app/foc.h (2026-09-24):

/*
 * foc.h - motor control state shared between the 20 kHz loop and the rest
 * of the application.
 *
 * The main loop never touches the PWM directly. It writes setpoints and a
 * state request into `foc`, and the control interrupt acts on them.
 */
#pragma once
#include <stdint.h>

/* drive states */
enum { ST_BOOT, ST_IDLE, ST_CAL, ST_RUN, ST_FAULT };

/* control modes while running */
enum { MODE_TORQUE = 1, MODE_SPEED = 2 };

/* state requests from the main loop */
enum { REQ_NONE, REQ_IDLE, REQ_TORQUE, REQ_SPEED, REQ_CAL };

/* fault bits (latched until cleared) */
#define F_OVERCURRENT  (1u << 0)
#define F_OVERVOLT     (1u << 1)
#define F_UNDERVOLT    (1u << 2)
#define F_OVERTEMP     (1u << 3)
#define F_DRV          (1u << 4)    /* gate driver reported a fault */
#define F_CURRENT_SUM  (1u << 5)    /* phase currents don't sum to zero */
#define F_CAL          (1u << 6)    /* calibration failed */
#define F_DRV_INIT     (1u << 7)    /* gate driver didn't accept its config */
#define F_OVERSPEED    (1u << 8)
#define F_NOT_CAL      (1u << 9)    /* run requested before calibration */
#define F_OFFSET       (1u << 10)   /* current sense offset out of range at boot */
#define F_ENCODER      (1u << 11)   /* encoder angle jumped */
#define F_NAN          (1u << 12)   /* control maths produced NaN */
#define F_STALL        (1u << 13)   /* full current but rotor not moving */

typedef struct {
    /* state */
    volatile uint8_t state, mode, req, cal_done;
    volatile uint16_t faults;

    /* setpoints and limits (written by the main loop) */
    volatile float cmd_iq, cmd_speed, i_limit, speed_limit;

    /* measurements and loop signals (written by the control loop) */
    volatile float ia, ib, ic, id, iq, vd, vq, id_ref, iq_ref, speed_ref;
    volatile float vbus, theta_e, theta_m, omega_m;
    volatile float t_fet, t_amb;
} foc_t;

extern foc_t foc;

void foc_init(void);
void foc_fault(uint16_t f);
void foc_clear_faults(void);
void foc_pll_reset(float theta_m);
uint32_t foc_isr_count(void);

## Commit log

2026-05-27 Almost done rev 1.1
    [bench_stm32_esc.kicad_pcb, bench_stm32_esc.kicad_sch]
2026-06-04 Revision 1.1
    [BOM-bench_stm32_esc.csv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]
2026-06-04 Added images of board
    [bench_stm32_esc.kicad_pcb]
2026-06-04 Add hardware section to README with images
    Added hardware section with images of the motor controller.
2026-06-04 Update Power MOSFETs specification in README
    Removed the quantity of Power MOSFETs listed in the specifications.
2026-06-04 Restructure repo, add .gitignore, remove build artifacts
    [BOM-bench_stm32_esc.csv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]
2026-06-04 Removed redundant files
    [BOM-bench_stm32_esc.csv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]
2026-06-12 Rev 1.2
    [bench_stm32_esc.kicad_pcb, bench_stm32_esc.kicad_sch]
2026-09-24 Bare-metal FOC firmware with HAL, SIL simulator, tests, dashboard and CI
    - Replace the CubeIDE project with a register-level CMSIS firmware for the
    STM32G474: 20 kHz d/q current PI with decoupling and 1.5 Ts delay
    compensation, 2 kHz speed PI, field-weakening PI, SVPWM, MA730 PLL,
    auto calibration stored in flash, DRV8353S setup/monitoring, FDCAN
    protocol, USB CDC framed telemetry and text commands, watchdog.
    - Split into portable app/ code over hal/hal.h, with hal/stm32g474 for the
    board and sim/ for a software-in-the-loop PMSM/inverter/sensor model.
    - foc_sim serves the same serial link over TCP for the dashboard.
    - C unit tests and SIL integration tests (ctest), Python dashboard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
    [adc.c, app.c, board.c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]
2026-09-24 Add Windows setup and dashboard launcher scripts
    - tools/setup.bat / setup.ps1: install missing prerequisites via winget,
    pick up STM32CubeCLT, build and run the C and Python tests, build the
    firmware when the ARM toolchain is available.
    - tools/dashboard.bat: start foc_sim + dashboard and open the browser.
    - Link the MinGW simulator statically so foc_sim.exe runs anywhere.
    Claude-Session: https://claude.ai/code/session_01BRZTqJEfzQvj4MZiHqSszE
2026-09-24 Readability pass and friendlier console commands
    - Every source file now starts with a short description, every function
    has a one-line comment, and the tricky bits have brief inline notes.
    - Simplified code: split the control ISR into small steps, table-free
    telemetry packing, generic queues in the simulator, clearer USB and
    gate driver code. No change to register setup or control behaviour.
    - Console: "motor <rpm>" spins in speed mode, "motor torque" + "iq <A>",
    "motor off". Requests that can't be honoured (not calibrated, faults
    latched, low bus voltage) are refused with a message instead of
    latching a fault.
    - Tests updated for the new command behaviour.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
    [adc.c, app.c, board.c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]
2026-09-24 Repo cleanup
    - Stop tracking the STM32CubeIDE .metadata workspace and ignore it.
    - Remove serial_plot.py (replaced by tools/dashboard/plot_motor.py).
    - Remove the broken controller_hardware/.history_trim submodule entry.
    - Move board images to visuals/ (large videos ignored) and fix the
    README links; update the README command examples.
    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
2026-09-24 Update hardware design files
    KiCad schematic/PCB/project and the JLCPCB gerbers, drill, BOM and CPL.
    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
    [BOM-bench_stm32_esc.csv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]
2026-09-24 Add dashboard demo GIF
    Recorded from the simulator: calibrate, 3000 rpm, load step, 9000 rpm
    with field weakening, reverse, locked-rotor stall fault and clear.
    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
2026-09-24 Rewrite README with board photos and real motor demo
